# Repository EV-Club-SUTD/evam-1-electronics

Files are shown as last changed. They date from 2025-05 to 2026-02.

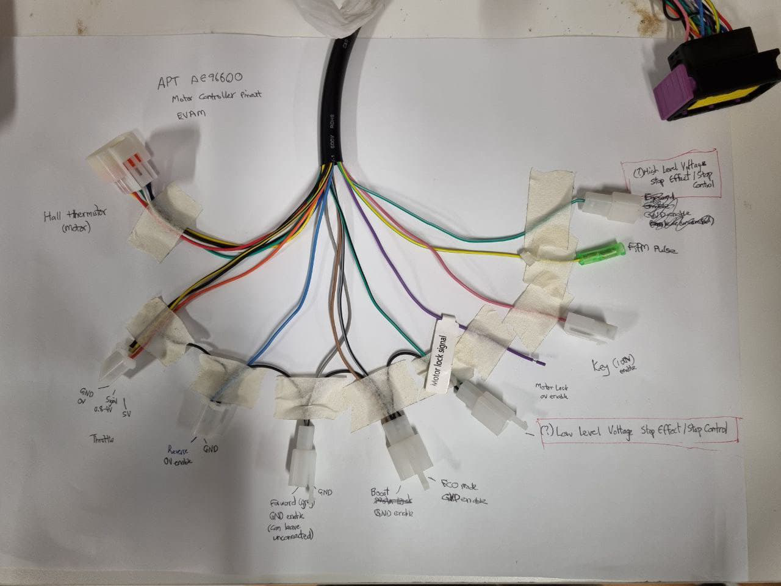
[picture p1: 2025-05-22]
docs/Datasheets/Motor Controller (QS Motor)/Original Controller Wire Harness Pinout.jpg

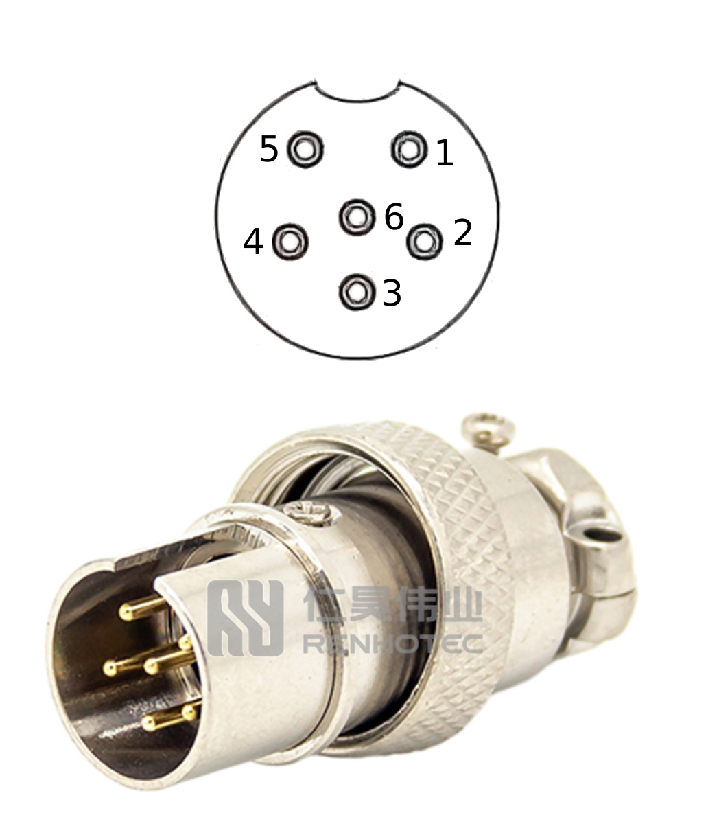
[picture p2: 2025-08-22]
docs/Wire Harness Diagrams/Master-Cable/img/GX16-Rev-pinout-cable.png

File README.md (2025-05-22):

# EVAM 1 Electronics Modules

> Design and manufacturing files for the EVAM 1's electrical and CAN bus system

<p align="center">

</p>

- [x] 🏎️ Automotive Hardware
- [ ] 🛞 Automotive Software
- [ ] 🖥️ Supporting Software and Simulations
- [ ] 📚 Code Library
- [ ] 🛠 Helper Script
- [x] 📖 Documentation / Datasheets
- [ ] ❓ Miscellaneous / Uncategorized

This repository contains the hardware design and manufacturing files for the EVAM 1's electrical system.  

## Directories

* `CANBus 2/Design` - Design files in KiCAD format
    * `/APPS` - Throttle position sensor PCB
    * `/BMS` - Battery Management System PCB
    * `/ECU` - Engine Control Unit PCB
    * `/HUD` - Heads up Display PCB
    * `/MCU_Double` - Motor Control Unit, double motor (for front motors)
    * `/MCU_Single` - Motor Control Unit, single motor (for rear motors)
    * `/SAS` - Steering Angle Sensor, originally meant for torque vectoring. Currently not used
* `CANBus 2/Manufacturing` - Manufacturing files (BOM, placement, and Gerbers)
* `CANBus 2/Electrical Layout` - Electrical layout design files, including block diagrams, to describe the high level overview of the entire electrical system
* `CANBus 2/Harness` - Cable harness design files and pictorial diagrams
* `Datasheets` - All the datasheets for the various components employed in the vehicle

## Documentation

Please refer to EVAM internal OneDrive for further documentation, including specific datasheets on the electrical system components

## Caveats

No known caveats yet

## Known issues

No known issues yet

## Contributing

If you encounter any issues with this repository, please do not hesitate to open an issue.

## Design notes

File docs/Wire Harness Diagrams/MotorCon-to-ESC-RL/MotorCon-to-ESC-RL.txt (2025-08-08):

Delphi / Aptiv 211PC249S0031 -> D
Molex KK 254 -> M
JST RCY -> J
DJ7061Y-2.3-11/21 -> H for hall sensor
    Connector side: 2 tabs facing up, numbered 1-6 from left to right, top to bottom. 

D C8 -> M 7 BLACK
D C7 -> H 1 YELLOW
D B8 -> H 5 WHITE
D A8 -> H 4 RED
D A7 -> H 3 BLUE
D B7 -> H 2 GREEN
D B6 -> M 3 YELLOW/GREEN
D A5 -> M 6 BROWN
D B5 -> M 5 BLACK/GREY
D C5 NOT IMPLEMENTED, SUPPOSED TO BE MOTOR LOCK
D A4 -> M 1 GREEN/BLACK
D B4 -> M 8 SKYBLUE
D B3 -> M 4 YELLOW/BLACK
D B1 -> J 1 PINK -> RED

Alphabetical order:

D A4 -> M 1 GREEN/BLACK
D A5 -> M 6 BROWN
D A7 -> H 3 BLUE
D A8 -> H 4 RED
D B1 -> J 1 PINK -> RED
D B3 -> M 4 YELLOW/BLACK
D B4 -> M 8 SKYBLUE
D B5 -> M 5 BLACK/GREY
D B6 -> M 3 YELLOW/GREEN
D B7 -> H 2 GREEN
D B8 -> H 5 WHITE
D C5 NOT IMPLEMENTED, SUPPOSED TO BE MOTOR LOCK
D C7 -> H 1 YELLOW
D C8 -> M 7 BLACK

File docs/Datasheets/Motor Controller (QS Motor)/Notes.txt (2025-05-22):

Battery to 12V controller that we have:
https://www.aliexpress.com/item/32908843079.html?pdp_ext_f=%7B%22ship_from%22:%22%22,%22sku_id%22:%2265947884391%22%7D&sourceType=fd&&scm=1007.28480.226530.0&scm_id=1007.28480.226530.0&scm-url=1007.28480.226530.0&pvid=7cc42ead-edf1-4f54-b0ab-460614838952&utparam=%7B%22process_id%22:%22110%22,%22x_object_type%22:%22product%22,%22pvid%22:%227cc42ead-edf1-4f54-b0ab-460614838952%22,%22belongs%22:[%7B%22id%22:%22812237%22,%22type%22:%22dataset%22%7D],%22scm%22:%221007.28480.226530.0%22,%22tpp_buckets%22:%2221669%230%23186385%230_21669%234190%2319160%23261_15324%230%23132599%230%22,%22x_object_id%22:%2232908843079%22%7D&spm=a2g0o.11810135.productlist.0

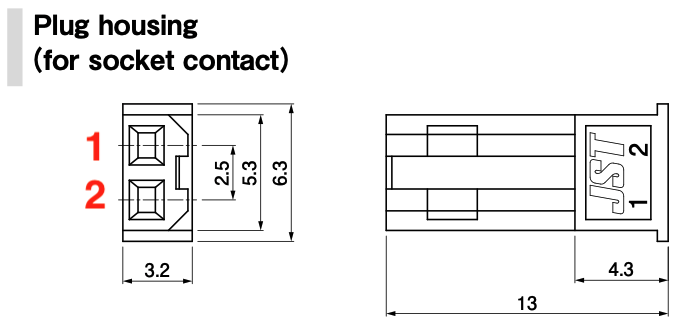
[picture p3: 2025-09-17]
docs/Wire Harness Diagrams/MotorCon-to-ESC-RL/img/JST-RCY-pinout-plug.png

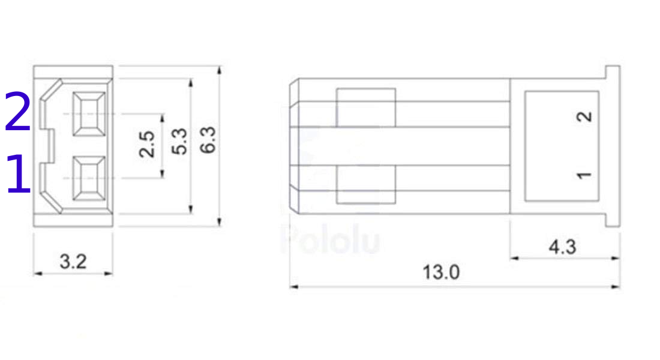
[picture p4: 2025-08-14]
docs/Wire Harness Diagrams/Master-Cable/img/JST-RCY-pinout.png

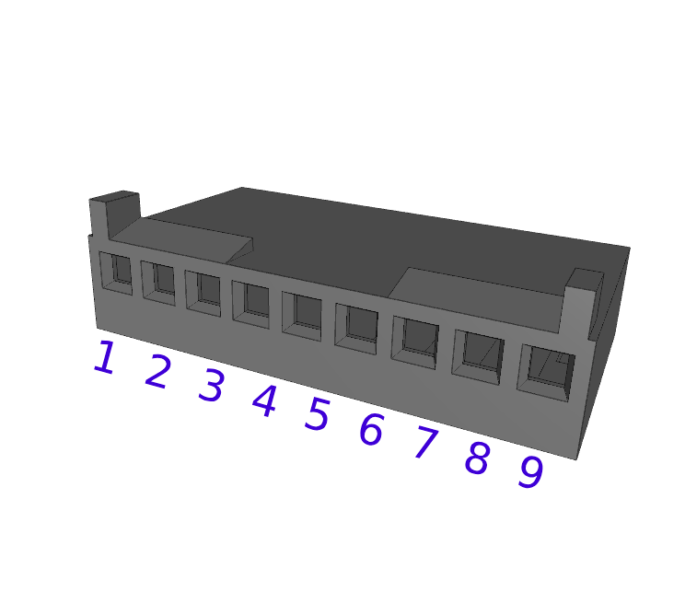
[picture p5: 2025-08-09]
docs/Wire Harness Diagrams/MotorCon-to-ESC-RL/img/MolexKK254-9-pinout.png

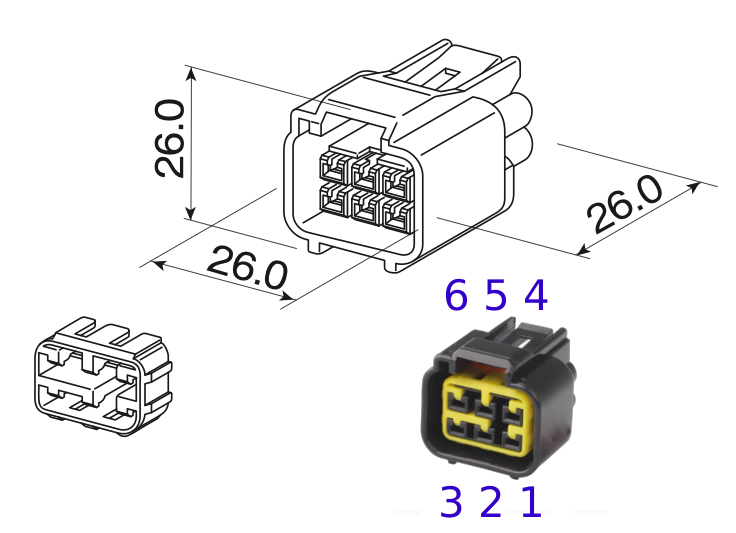
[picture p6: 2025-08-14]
docs/Wire Harness Diagrams/Master-Cable/img/FW-C-6F-B-pinout.png

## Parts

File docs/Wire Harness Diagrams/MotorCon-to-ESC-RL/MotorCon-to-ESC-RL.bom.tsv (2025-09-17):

Id | Description | Qty | Unit | Designators | Manufacturer | MPN | Supplier | SPN
1 | Cable, 1 x 22 AWG | 0.1 | m | W2
2 | Connector, Aptiv SICMA, Female, 24 pins | 1 |  | C1 | Aptiv (formerly Delphi) | 211PC249S0031 | Mouser | 649-211PC249S0031
3 | Connector, Furukawa RFW, Female, 6 pins | 1 |  | C2 | Furukawa | FW-C-6F-B | Aliexpress | DJ7061Y-2.3-11
4 | Connector, Heat shrink solder joint, 22 AWG | 1
5 | Connector, JST RCY, Plug, 2 pins | 1 |  | C4 | JST | SYR-02T | DigiKey | 455-2653-ND
6 | Connector, Molex KK254, Female, 9 pins | 1 |  | C3 | Molex | 22013097 | DigiKey | WM2007-MD
7 | Wire, 22 AWG, BK | 1 | m | W1
8 | Wire, 22 AWG, BN | 0.5 | m | W1
9 | Wire, 22 AWG, BU | 0.5 | m | W1
10 | Wire, 22 AWG, GN | 0.5 | m | W1
11 | Wire, 22 AWG, GNBK | 0.5 | m | W1
12 | Wire, 22 AWG, GYBK | 0.5 | m | W1
13 | Wire, 22 AWG, PK | 0.5 | m | W1
14 | Wire, 22 AWG, RD | 0.5 | m | W1
15 | Wire, 22 AWG, VT | 0.5 | m | W1
16 | Wire, 22 AWG, WH | 0.5 | m | W1
17 | Wire, 22 AWG, YE | 0.5 | m | W1
18 | Wire, 22 AWG, YEBK | 0.5 | m | W1
19 | Wire, 22 AWG, YEGN | 0.5 | m | W1

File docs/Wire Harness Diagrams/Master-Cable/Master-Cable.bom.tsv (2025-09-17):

Id | Description | Qty | Unit | Designators | Manufacturer | MPN | Supplier | SPN
<<<<<<< HEAD
1 | Cable, 1 x 22 AWG | 0.5 | m | W10, W2, W4, W6, W7
2 | Cable, 2 x 22 AWG | 0.1 | m | W3
3 | Cable, 6 x 22 AWG | 0.5 | m | W1
4 | Connector, GX16-6 Reverse Type, Male, 6 pins | 1 |  | C1 | Renhotec | GX16-A-6-P | Aliexpress | 1005008016363970
5 | Connector, Heat shrink solder joint, 22 AWG | 6
6 | Connector, JST RCY, Female, 2 pins | 2 |  | C3, C5 | JST | SYR-02T | DigiKey | 455-2653-ND
7 | Connector, JST RCY, Male, 2 pins | 1 |  | C4 | JST | SYR-02T | DigiKey | 455-2653-ND
8 | Connector, M12 A-key, Female, 6 pins | 1 |  | C2 | CANZ | M12-S-GWB | Taobao
9 | Wire, 22 AWG, BN | 0.1 | m | W5
=======
1 | Cable, 1 x 22 AWG | 0.4 | m | W5, W6, W7, W8
2 | Cable, 2 x 22 AWG | 0.2 | m | W2, W9
3 | Cable, 6 x 22 AWG | 0.5 | m | W1
4 | Connector, E-Stop Switch, 22 AWG | 1
5 | Connector, Fork terminal, 22 AWG, BK | 1
6 | Connector, Fork terminal, 22 AWG, RD | 1
7 | Connector, GX16-6 Reverse Type, Male, 6 pins | 1 |  | C1 | Renhotec | GX16-A-6-P | Aliexpress | 1005008016363970
8 | Connector, Heat shrink solder joint, 22 AWG | 6
9 | Connector, JST RCY, Plug, 2 pins | 4 |  | C4, C5, C7, C8 | JST | SYR-02T | DigiKey | 455-2653-ND
10 | Connector, JST RCY, Receptacle, 2 pins | 2 |  | C3, C6 | JST | SYR-02T | DigiKey | 455-2653-ND
11 | Connector, M12 A-key, Female, 6 pins | 1 |  | C2 | CAZN | M12-S-GWB | Taobao
12 | Connector, exposed section, 22 AWG | 3
13 | Wire, 22 AWG, BK | 0.2 | m | W10, W4
14 | Wire, 22 AWG, BN | 0.1 | m | W4
15 | Wire, 22 AWG, RD | 0.2 | m | W10, W4
16 | Wire, 22 AWG, WH | 0.1 | m | W4
>>>>>>> 582522ff65bb673bbe9b758eed1d0406d6d0a58b

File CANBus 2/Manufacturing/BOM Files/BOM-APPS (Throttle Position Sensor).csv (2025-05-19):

Comment | Designator | Footprint | LCSC
8MHz | Y1 | Crystal_SMD_HC49-SD | C12674
0.1uF | C1,C2 | C_0603_1608Metric | C14663
22pF | C5,C6 | C_0603_1608Metric | C1653
MCP2515-xST | U1 | TSSOP-20_4.4x6.5mm_P0.65mm | C185941
120 | R3 | R_0603_1608Metric | C22787
10k | R4 | R_0603_1608Metric | C25804
Conn_01x03_Pin | J4 | Molex_KK-254_AE-6410-03A_1x03_P2.54mm_Vertical | C2982032
10uF/16V | C3 | CP_EIA-3216-18_Kemet-A | C7171
TJA1051T | U2 | SOIC-8_3.9x4.9mm_P1.27mm | C92211

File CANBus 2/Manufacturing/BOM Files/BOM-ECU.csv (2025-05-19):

Comment | Designator | Footprint | LCSC
8MHz | Y1 | Crystal_SMD_HC49-SD | C12674
MCP2515-xST | U1 | TSSOP-20_4.4x6.5mm_P0.65mm | C15193
0.1uF | C3,C4,C6 | C_0603_1608Metric | C1525
22pF | C1,C2 | C_0603_1608Metric | C1653
120 | R4 | R_0603_1608Metric | C22787
10k | R3 | R_0603_1608Metric | C25804
Conn_01x03_Pin | J1 | Molex_KK-254_AE-6410-03A_1x03_P2.54mm_Vertical | C2982032
10uF/16V | C5 | CP_EIA-3216-18_Kemet-A | C7171
24k/1W | R1,R2 | R_2512_6332Metric | C728156
SN74LVC1G14DBV | U4 | SOT-23-5 | C7835
6N137S | U3 | SMDIP-8_W9.53mm | C898988
TJA1051T | U2 | SOIC-8_3.9x4.9mm_P1.27mm | C92211

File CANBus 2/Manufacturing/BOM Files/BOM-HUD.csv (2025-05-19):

Comment | Designator | Footprint | LCSC
SN65HVD230 | U2 | SOIC-8_3.9x4.9mm_P1.27mm | C12084
SW_SPDT | SW1 | SW_SPDT_MT-0-103-F001-T000-RS | C1788498
1M | R6 | R_1206_3216Metric | C17927
10k | R1,R2,R3,R4,R5,R7 | R_0603_1608Metric | C25804
Conn_01x02_Pin | J5,J6,J7,J8 | Molex_KK-254_AE-6410-02A_1x02_P2.54mm_Vertical | C2982031
Conn_01x04_Pin | J4 | Molex_KK-254_AE-6410-04A_1x04_P2.54mm_Vertical | C2982033
Conn_01x09_Pin | J1 | Molex_KK-254_AE-6410-09A_1x09_P2.54mm_Vertical | C2982038

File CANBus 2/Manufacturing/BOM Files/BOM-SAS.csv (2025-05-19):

Comment | Designator | Footprint | LCSC
8MHz | Y1 | Crystal_SMD_HC49-SD | C12674
0.1uF | C1,C2 | C_0603_1608Metric | C14663
10uF | C3 | C_0805_2012Metric | C15850
22pF | C5,C6 | C_0603_1608Metric | C1653
MCP2515-xST | U2 | TSSOP-20_4.4x6.5mm_P0.65mm | C185941
120 | R2 | R_0603_1608Metric | C22787
10k | R1 | R_0603_1608Metric | C25804
Conn_01x03_Pin | J1 | Molex_KK-254_AE-6410-03A_1x03_P2.54mm_Vertical | C2982032
Conn_01x04_Pin | J2 | Molex_KK-254_AE-6410-04A_1x04_P2.54mm_Vertical | C2982033
TJA1051T | U1 | SOIC-8_3.9x4.9mm_P1.27mm | C92211

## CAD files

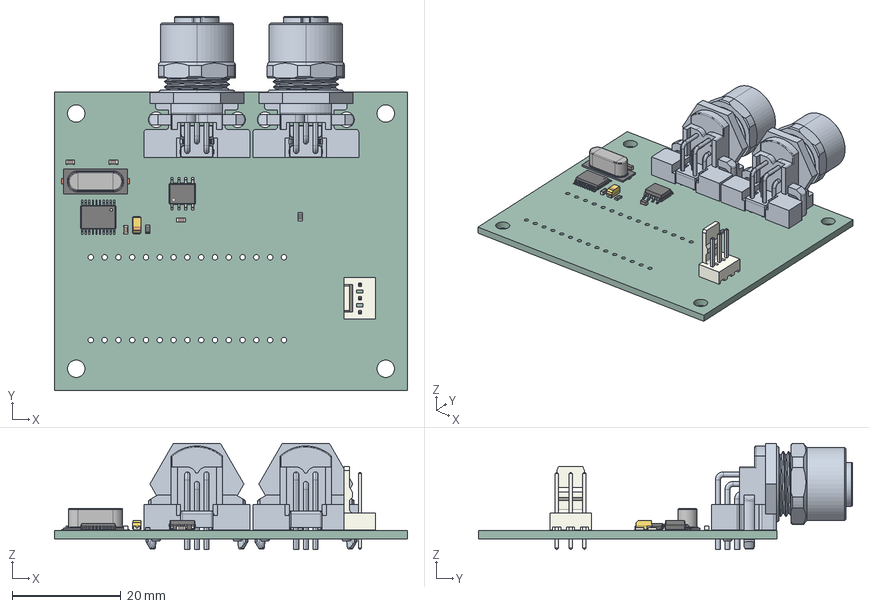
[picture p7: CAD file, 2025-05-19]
CANBus 2/Design/APPS (Throttle Position)/APPS (Throttle Position Sensor).step
65.0 x 68.9 x 19.6 mm
APPS (Throttle Position Sensor) PCB

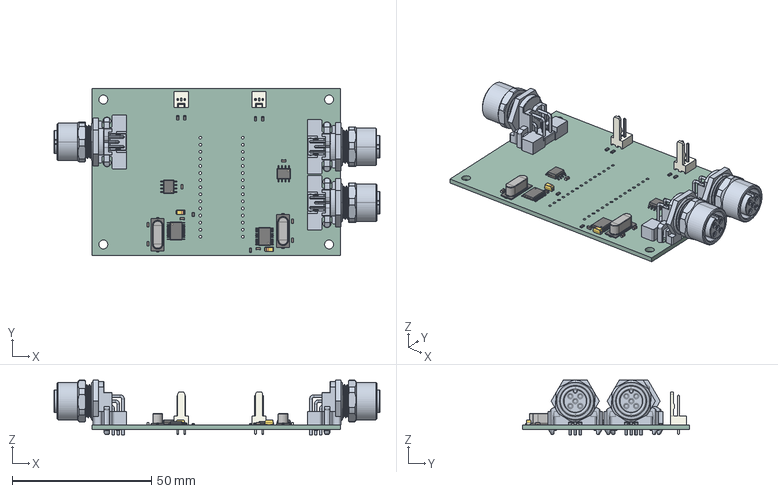
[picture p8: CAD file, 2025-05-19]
CANBus 2/Design/BMS/BMS.step
117.0 x 60.0 x 19.6 mm
BMS PCB

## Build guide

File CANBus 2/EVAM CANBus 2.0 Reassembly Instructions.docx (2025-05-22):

# EVAM CANBus 2.0 Reassembly Instructions

Last updated: 11 Feb 2025

Table of Contents

Version history

V1.0: First draft published 11 Feb 2025.

## 1 Setup Instructions

- Ensure that all high temperature works (e.g. Welding) on mainframe are completed before rewiring of car.
- Wiring can be done before the battery is placed back into the car. No need to install the battery first
- Remove the two seats (note that front seat has spacers for wires to run below, while the rear seat does not have spacers) to make room for wiring.
- If you need wiring guidance, please refer to the Wiring and Brake Overview Diagram (https://sutdapac-my.sharepoint.com/:b:/r/personal/ev_club_sutd_edu_sg/Documents/EVAM%201/EVAM/Motor,%20Controller,%20Battery/Wiring/EVAM%20Electrical,%20CANBU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) PDF file.

CRITICAL WARNING

- Rewiring can be dangerous if improperly done! There is a genuine risk of fire and electrical shock if wiring is not done properly once the battery is connected. Always double/triple check your connections once completed.
- The chassis is grounded at a 0V potential. This means that any stray wire that accidentally contacts the chassis may cause a serious short circuit incident!
- Always double check that there are ZERO frayed wires and take note that some of the dashboard elements such as the Estop signals are 100V signals directly coming from the battery.
- There HAVE BEEN incidents where the 100V Estop signal inadvertently touched the chassis resulting in an electrical arc incident, which thankfully was brief and did not result in serious harm. DO NOT be the first casualty!

## 2 High Power Lines Installation

The high-power lines are responsible for conducting large currents from the battery to the motors.

Ensure that the bus bar panel is screwed into the blast plate. There should be a wire for grounding the chassis. Uncoil all overlapping/intersecting wires.

Below shows a picture of the components on the bus bar panels. Black high-power lines leading to the motor controllers are labelled front, rear, left and right. Replace the labels if they are missing or broken.

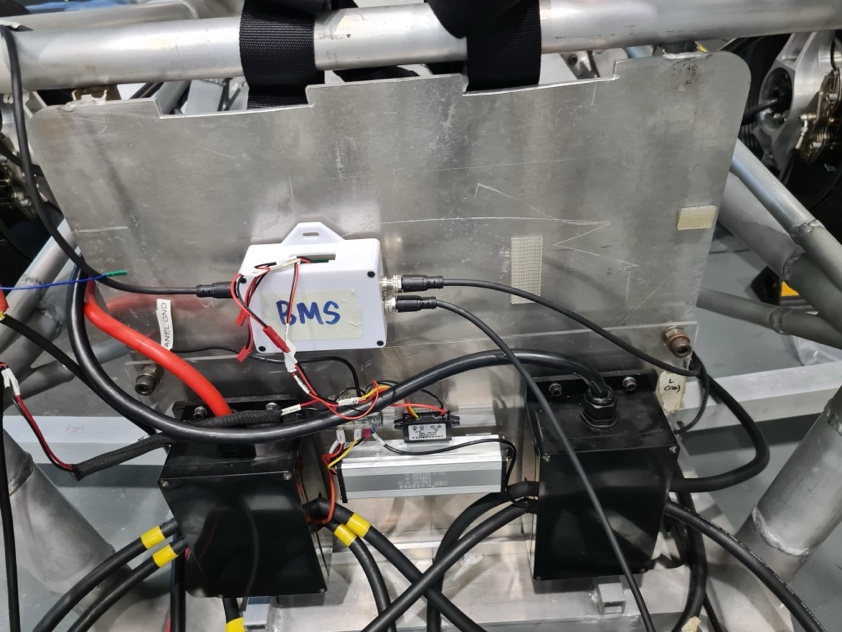
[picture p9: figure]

Figure 1: Bus bar panel mounted to the blast plate The BMS CAN module depicted in the picture is mounted later.

Figure 2: Diagram of the terminal block on the busbar panel

Within the busbar panel, there is a terminal block used to link some of the voltage lines together. This terminal block should eventually be replaced with something more robust.

The thin 100V lines serve 2 purposes: transport the 100V output directly from the battery to a 12V regulator to provide 12V electricals, and to provide the signal for motor Estop.

(insert wiring diagram on how cable is typically placed in the car)

## 3 Motor Controllers' installation

Attach motor controllers to main frame of car and wire the motors according to the color codes. Inspect all connectors and cables for motor controllers to ensure no wires are frayed.

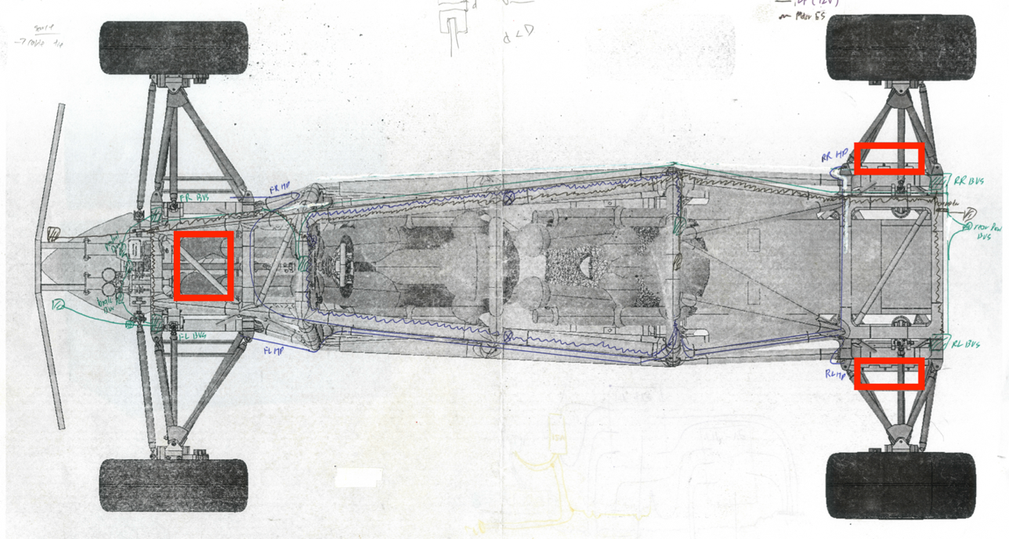
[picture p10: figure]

Figure 3: Motor controller locations

Motor controllers should be labelled appropriately with rear or front, as THEY HAVE DIFFERENT PINOUTS. Failure to maintain front/rear will result in failure of individual motor drivers.

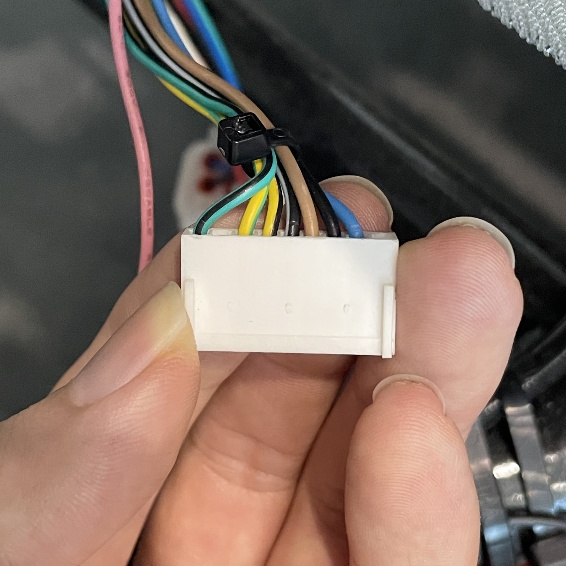
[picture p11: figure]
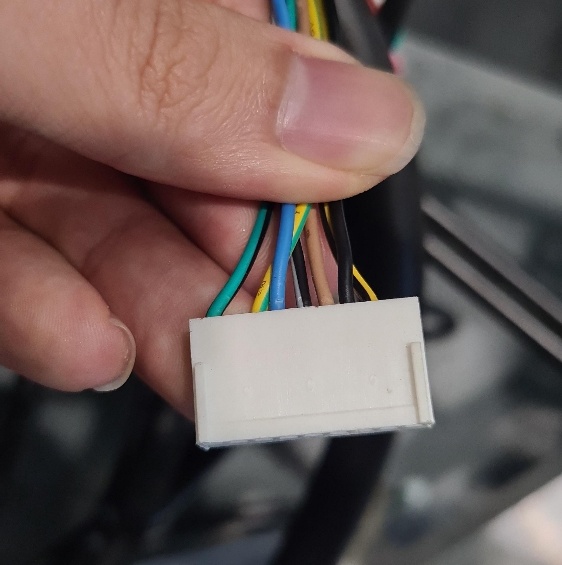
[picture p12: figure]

Figure 4 (left): example of a rear motor controller connector

Figure 5 (right): Example of a front motor controller

(insert picture on how to connect hall connector of motor controller to wheel hub motors)

(insert picture of high-power lines attached to motor controllers)

## 4 Understanding the Master Cable

The Master Cable is a specially made cable that runs the entire length of the vehicle, starting at the battery’s CAN connector and ends at the front dashboard, with a split in the middle to accommodate the battery Estop button in the middle of the vehicle.

This cable is designed to handle the following functions:

- Motor Estop
- Battery Estop
- Battery CAN bus

Figure 6: Basic hand drawn diagram of the Master Cable

The Master Cable should be replaced as soon as possible with a more professional solution as the bend radii of several inner cables are too short, potentially causing breakages and dangerous operating conditions.

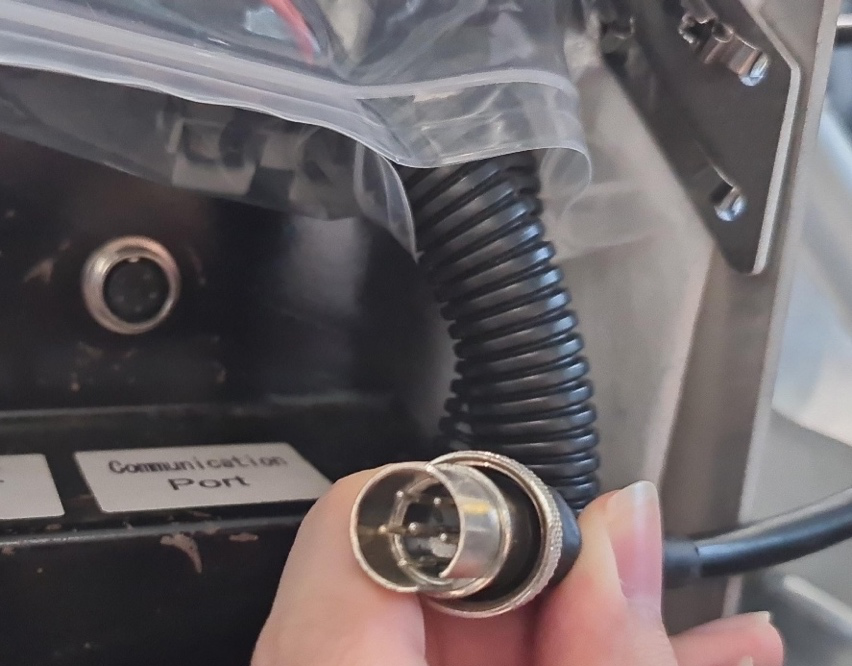
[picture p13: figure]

Figure 7: Battery CAN connector

The Master Cable chiefly contains the following signals stemming from the Battery CAN Connector (see above figure).

- Pin 5: CAN High
- Pin 6: CAN Low
- Pin 3: unknown red cable (possibly 100V)
- Pin 4: unknown black cable (possibly GND)
- Pin 1: battery estop switch
- Pin 2: battery switch

This bundle is then carried through the middle of the vehicle where it interfaces with the battery Estop switch:

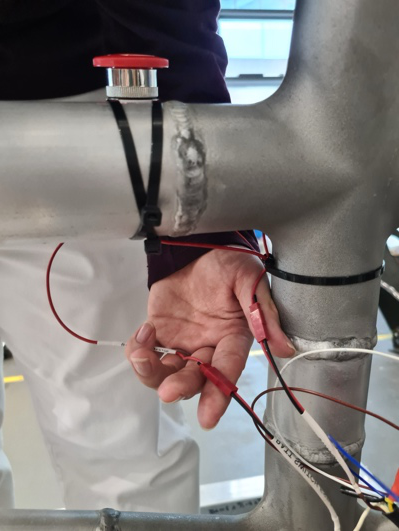
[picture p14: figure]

Figure 8: Battery Estop switch

After this, the bundle is split and additional cables travels to the front for the battery switch on the dashboard (turn knob).

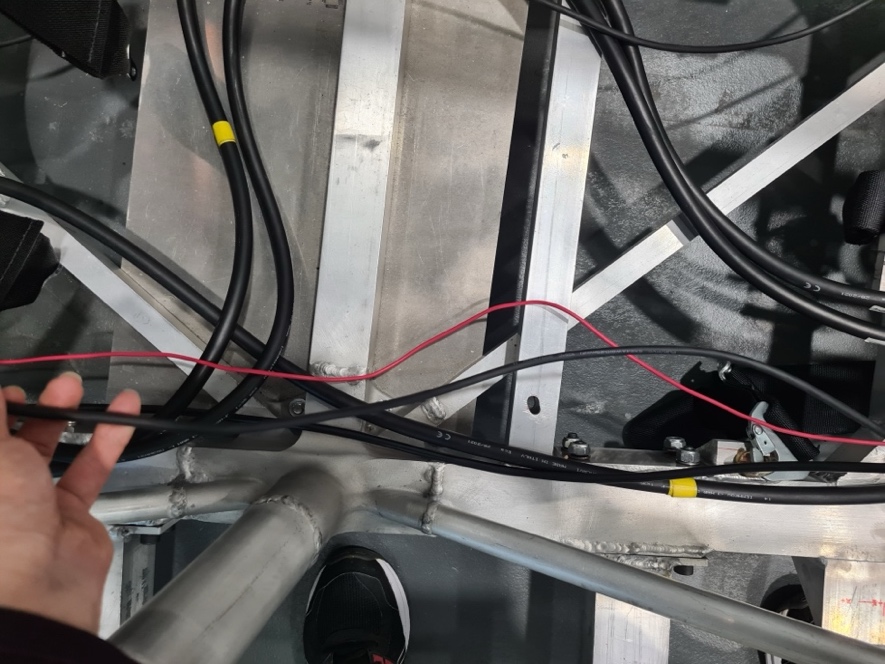
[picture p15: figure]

Figure 9: Black cable being held is the Master Cable as it travels from the middle Estop to the dashboard battery switch

## 5 CAN Modules Installation (8 Modules in Total)

### 5.1 BMS CAN module installation (rear)

Using a M2 Allen Key, unscrew the screws on the enclosures to access the PCB. Connect the wires through the holes found the enclosures and screw the lid back on.

Connect the 5V and 12V sense lines from the CAN bus panel to the BMS PCB.

Figure 10: BMS CAN node wiring before attachment to bus bar panel

Attach the Battery Side CAN using the shortest M12 cable possible to the Master Cable’s battery connector, which runs to the battery’s internal system

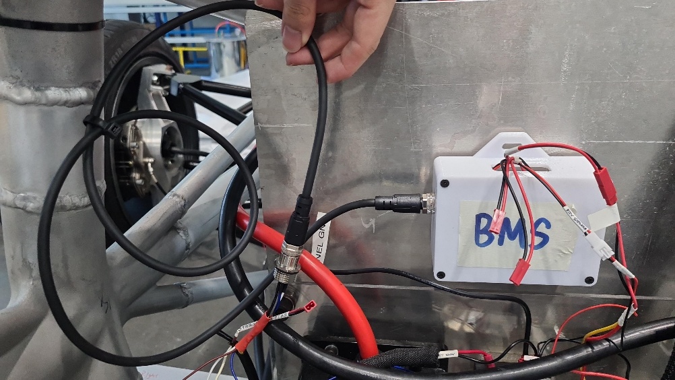
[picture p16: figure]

Figure 11: Connecting the BMS CAN port to the Master Cable

### 5.2 Motor CAN module installation (rear)

We will start with the motor node that has CAN termination, which has blackened corner marking on its top cover. This is installed on the rear left motor controller.

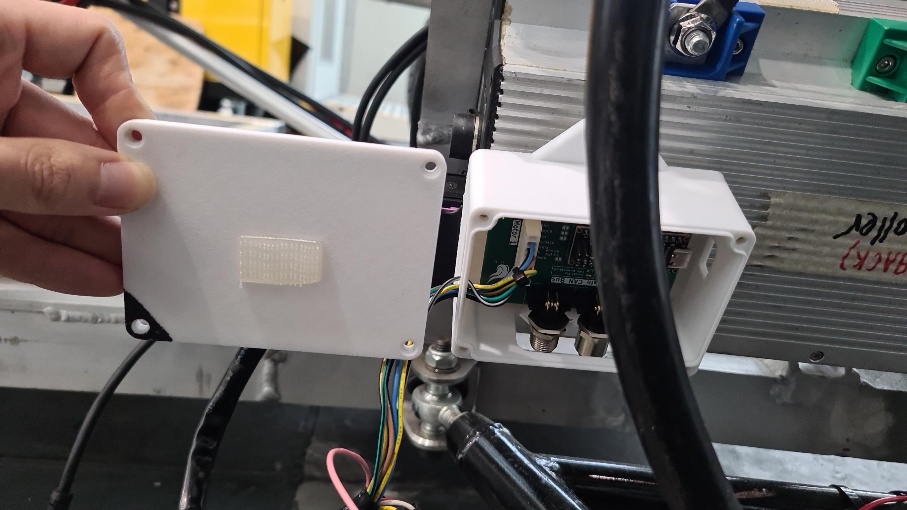
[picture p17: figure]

Figure 12: Rear left motor CAN node with black corner markings

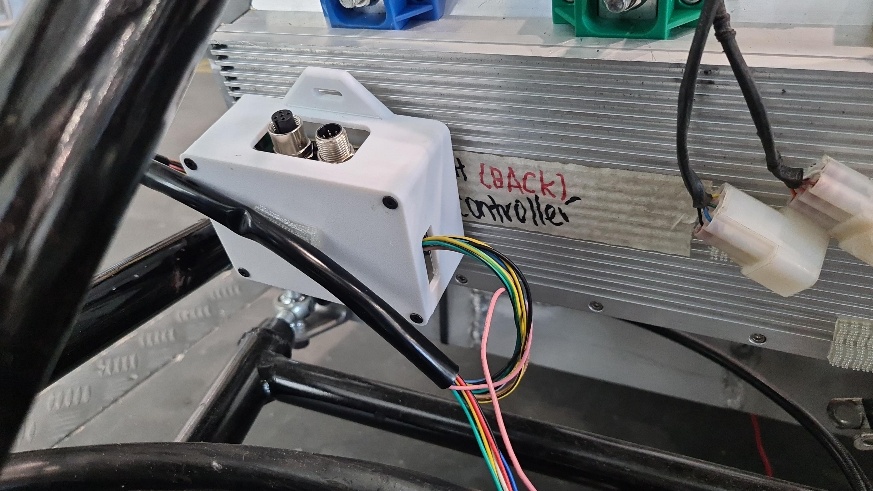
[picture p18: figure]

Figure 13: Rear right motor CAN node without markings

### 5.3 Motor CAN module installation (front)

The front of the vehicle has a dual motor CAN node. Connect both motor controllers to the CAN node and fasten them if necessary.

Figure 14: Mounting the Front Motor Controller

### 5.4 Throttle CAN and Steering Angle modules installation (front)

Attach the enclosures of the two modules to the front of the car near the brake and throttle pedals.

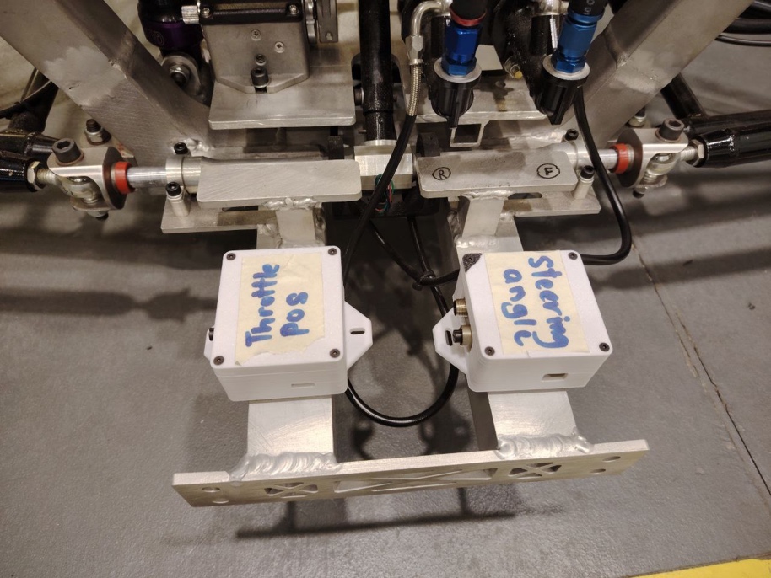
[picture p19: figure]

Figure 15: Placement of Throttle and Steering Angle Modules

Using a M2 Allen Key, unscrew the screws on the enclosures to access the PCB. Connect the wires through the holes found the enclosures and screw the lid back on.

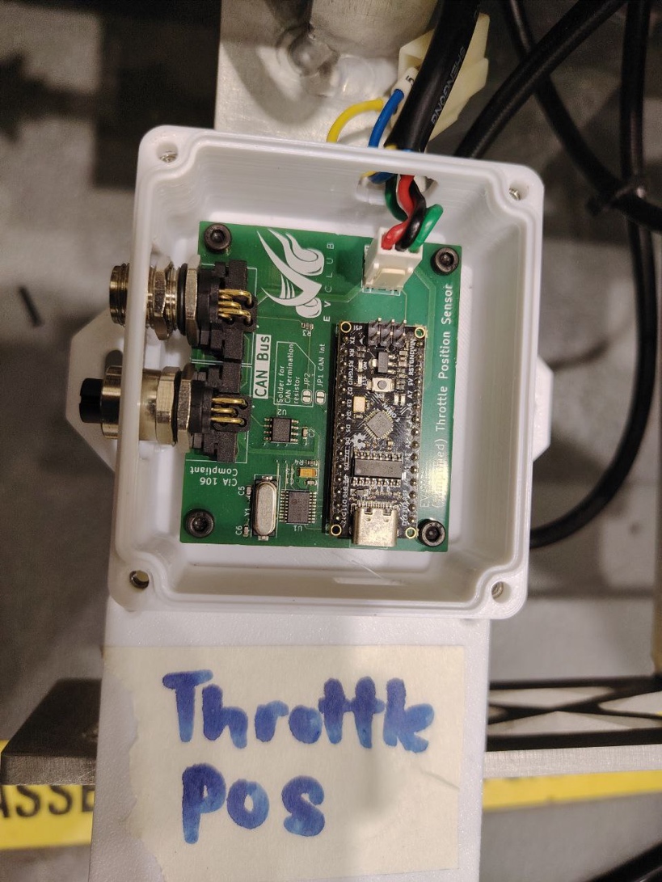
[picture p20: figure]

Figure 16: Throttle Position Sensor PCB wiring

### 5.5 HUD and ECU CAN modules installation (front)

Attach the enclosures of the two modules to the front of the car near the brake and throttle pedals. Wire up the HUD module appropriately according to the image below.

Take extra care to ensure that the right connectors are linked to the right sockets as the Estop is a 100V signal and WILL fry the module if connected incorrectly!!

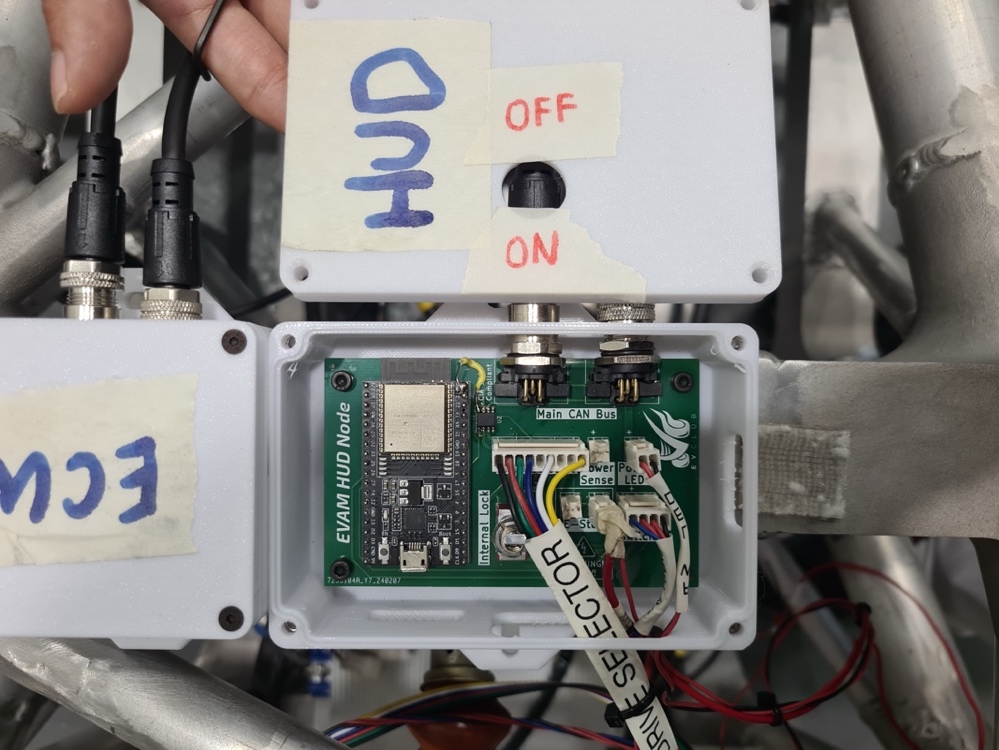
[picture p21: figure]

Figure 17: HUD PCB wiring. Note the masking taped wire is the high voltage Estop signal

Figure 18: ECU and HUD module placements

Once this is complete, we can begin wiring up all the modules.

### 5.6 CAN Bus Black Cables Connection to all nodes

1. Starting at the rear left motor node (which is a termination node, marked by the black edge colored by a marker), we run the cable to the rear right motor node.

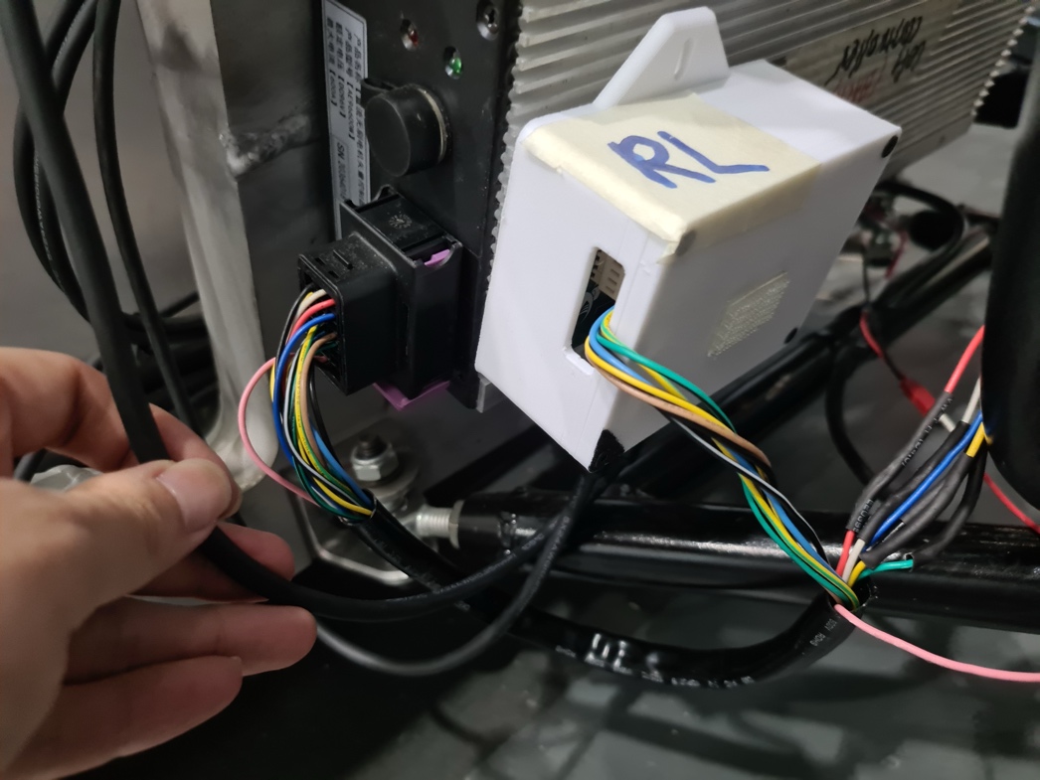
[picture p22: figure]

2. Run the cable from the rear left motor node to the rear right motor node across the top of the vehicle

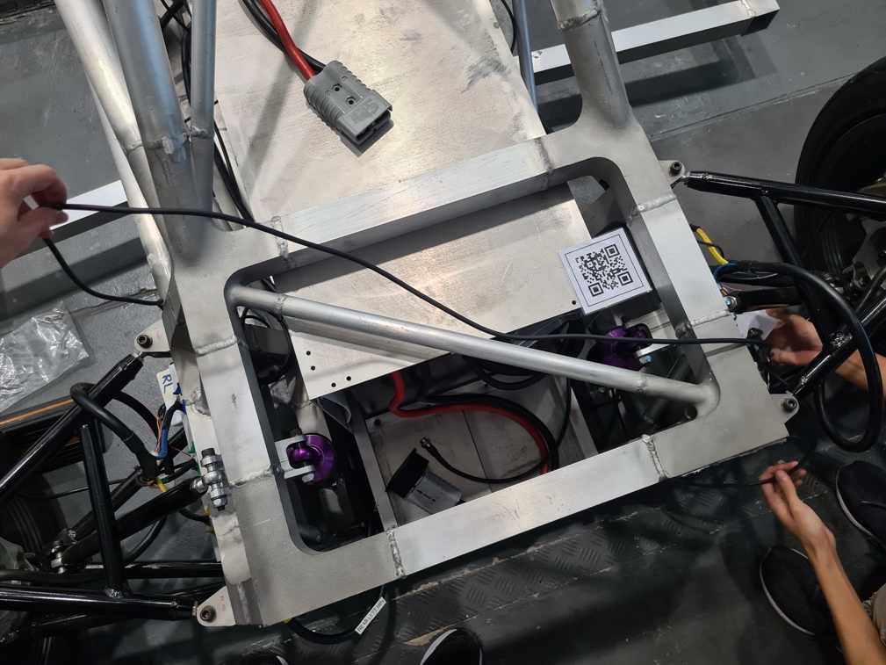
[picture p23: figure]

3. Run a long cable from the right rear motor module to the front of the vehicle and connect it to the HUD node.

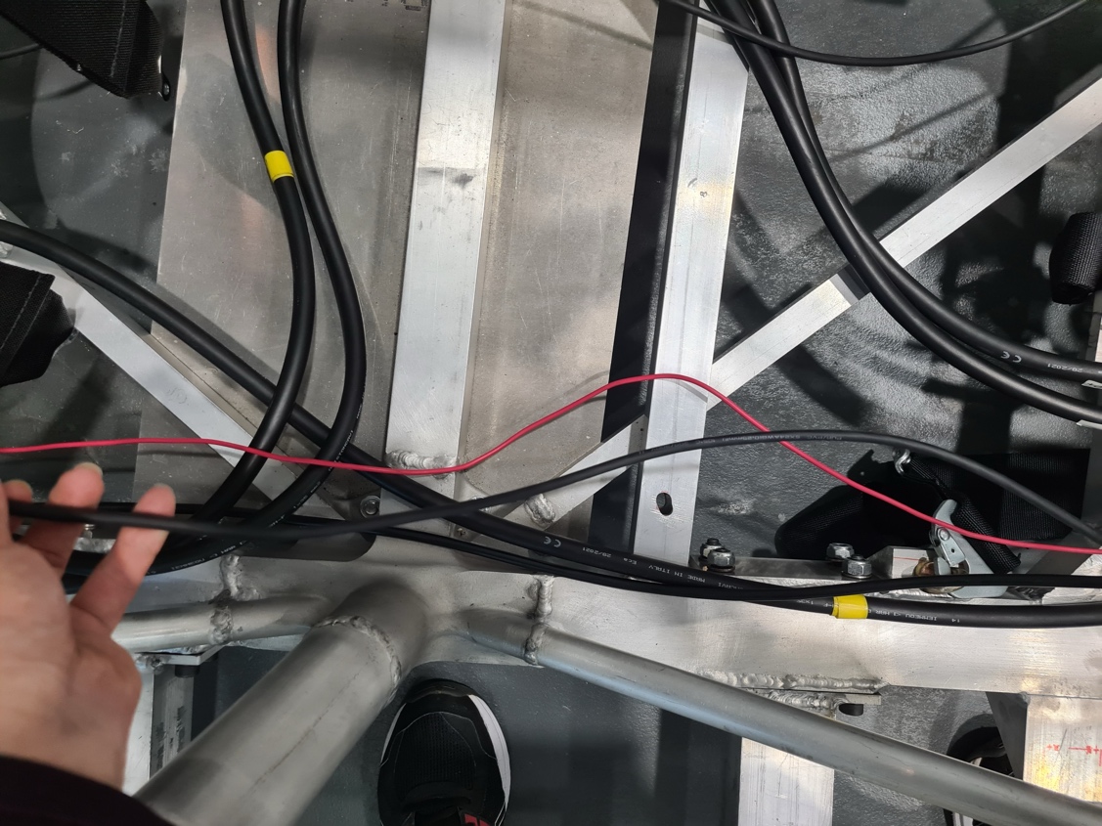
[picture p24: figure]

4. Use the shortest possible cable to connect the HUD and ECU modules together.
5. Run the ECU cable to the throttle position sensor
6. Link the throttle position sensor and the steering angle sensor modules together.
7. Run another medium length cable from the steering angle sensor to the front dual motor module

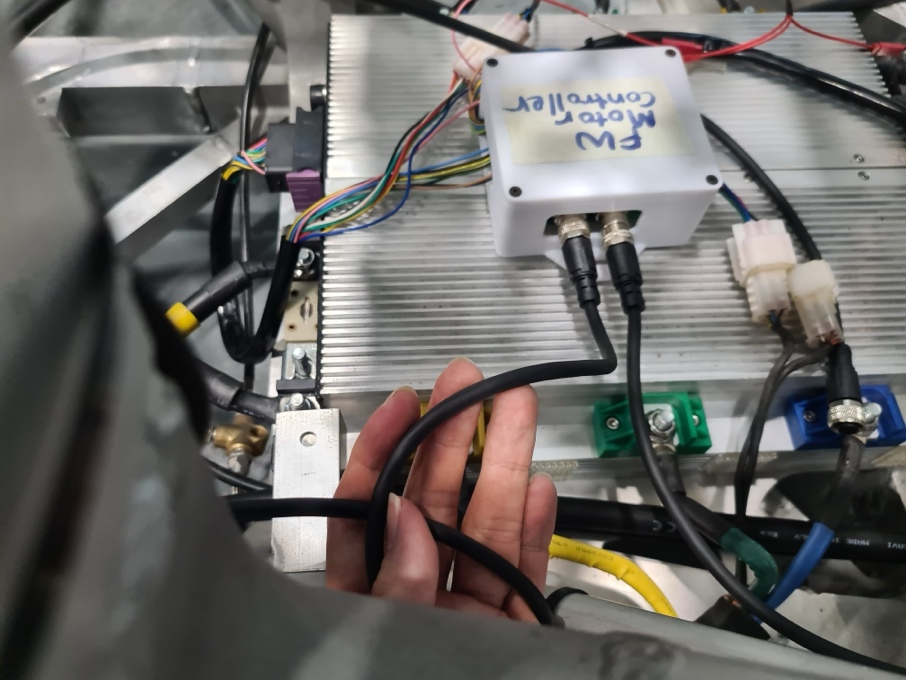
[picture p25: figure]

8. Wire the front dual motor module to the battery management system module. Finally, wire the BMS module to the rear left motor module mentioned in the 1st step and the CAN bus wiring is complete!

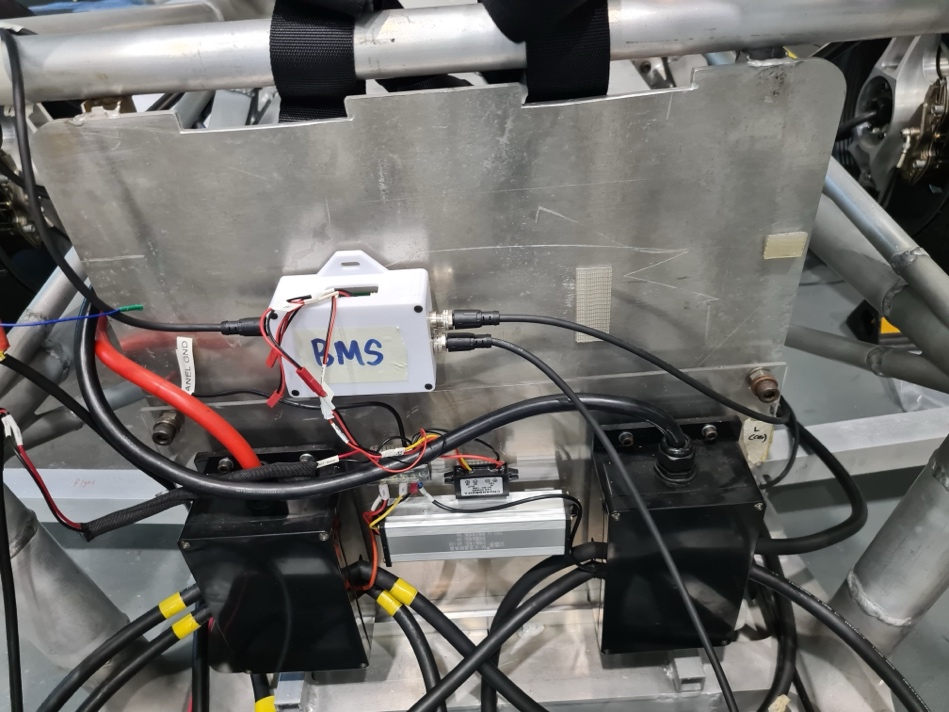
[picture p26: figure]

## 6 E-stop connection

### 6.1 Battery Estop

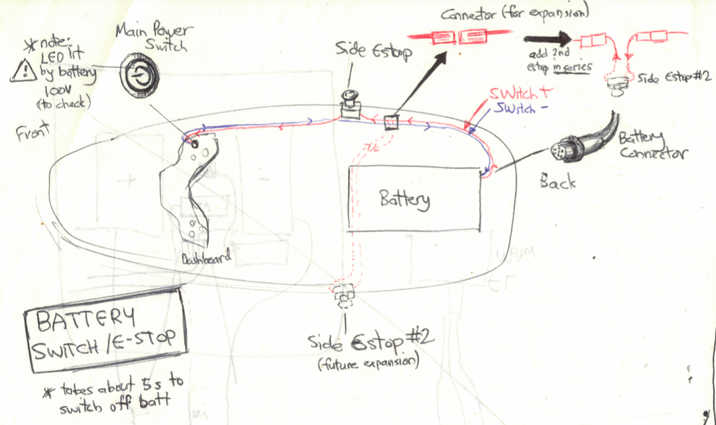
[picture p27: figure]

Figure 19: Battery E-stop diagram

The battery Estop system runs a single electrical signal in the following order:

- Battery Connector
- Estop button on the side of the vehicle
- Power switch on the front of the vehicle.

It is a relatively easy to install system as it only needs to connect at 3 points.

Figure 20: Rear of the Master Cable, which connects to the battery’s Communication Port

Once the Master Cable is installed into the vehicle (this is the cable that contains the battery signal connector, which is a proprietary “aviation style” connector instead of the standard M12 connector), the Estop button can be wired up as in the pictures below:

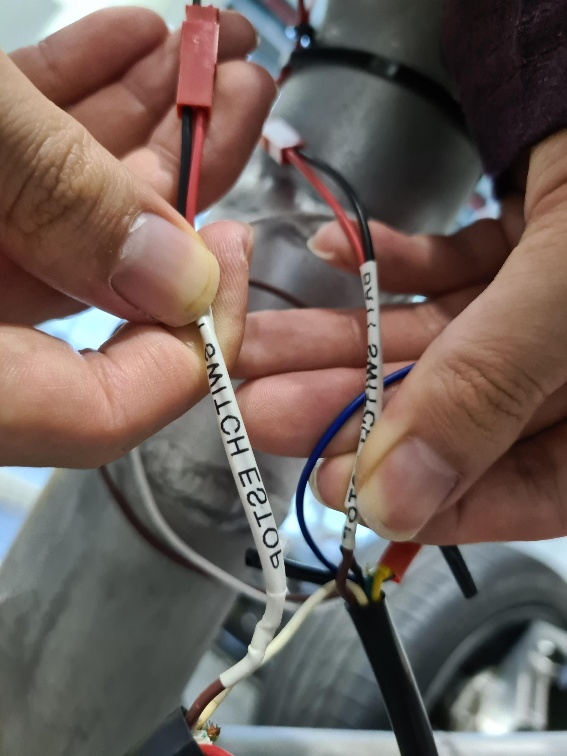
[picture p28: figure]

Figure 21 (left): Master Cable to Battery Estop switch on the side of the vehicle

Figure 22 (right): Master Cable to Battery Estop switch in the front of the vehicle

The red wire labelled ESTOP SWITCH must be wired to the front of the vehicle, where the red power switch is placed. The other wire labelled BATT ESTOP must be wired to the rear of the vehicle, where the battery’s signal cable is being plugged in.

### 6.2 Motor Estop

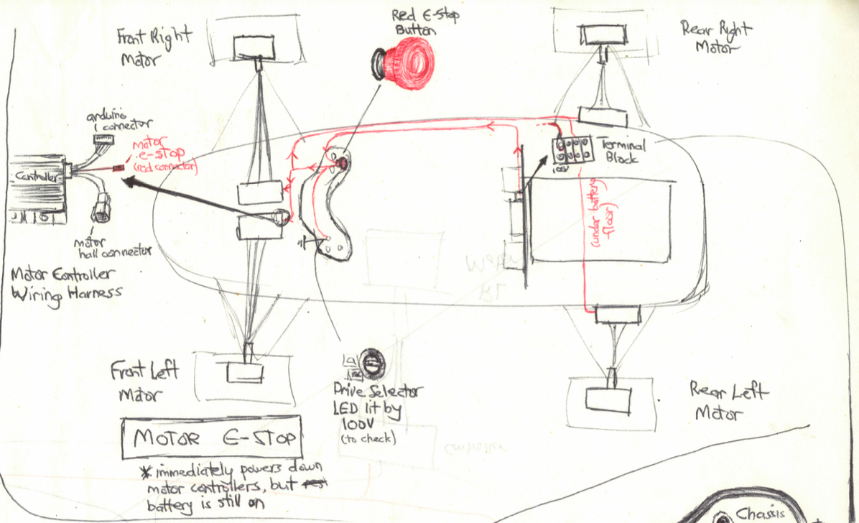
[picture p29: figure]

Figure 23: Motor Estop schematic

The Motor Estop is more complex, and is routed to the following places

- 100V from Terminal Block: This is where the 100V originates for the motor Estop signal
- Dashboard Estop button: root node, this button
- Front Left Motor Controller
- Front Right Motor Controller
- Rear Right Motor Controller
- Rear Left Motor Controller

The Motor Estop system is responsible for allowing the driver to assert a stop signal to all the motor controllers, allowing them to go into standby mode without having to power off the entire vehicle.

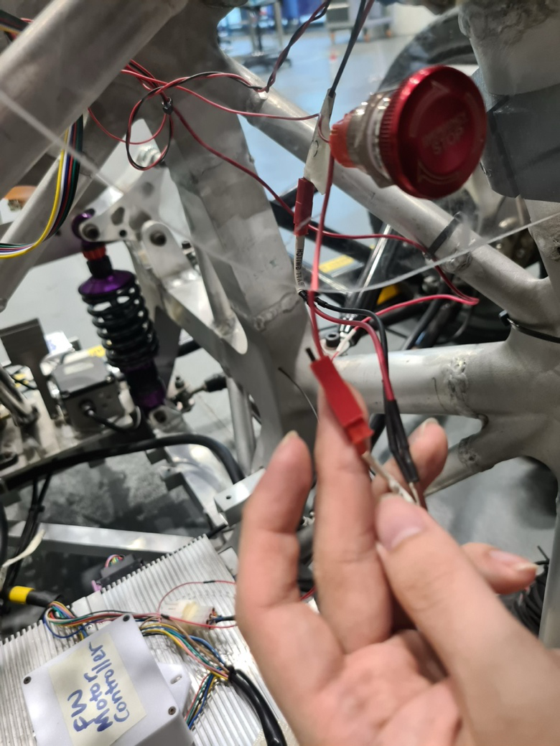
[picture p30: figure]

Figure 24: Front motor Estop button wiring

Figure 25: Front motor controllers wired to front Estop switch

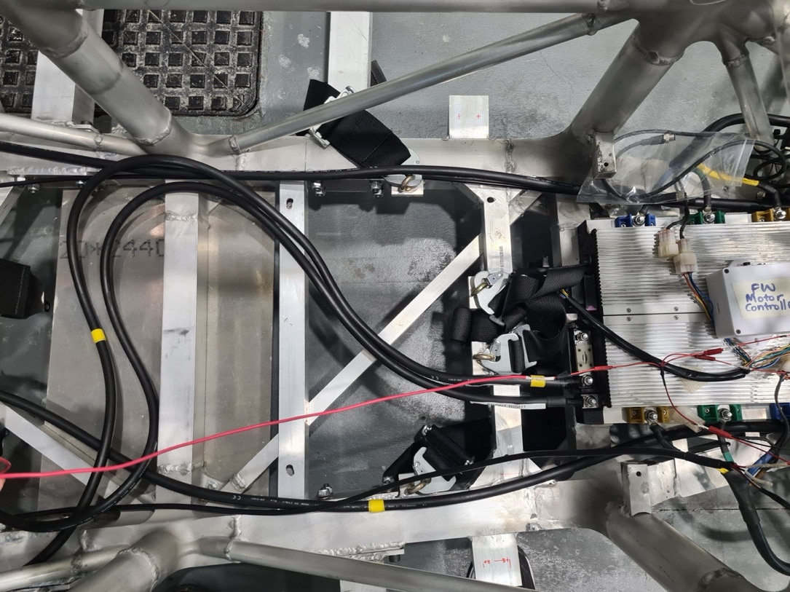
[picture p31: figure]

Figure 26: Red cable which conducts the Motor Estop signal going from the front controllers to the rear. Note the splice on the right side of this image

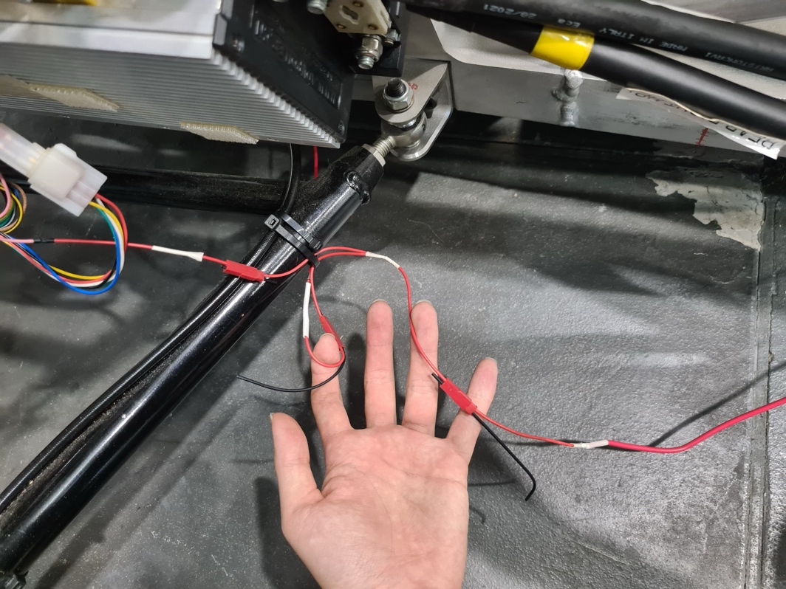
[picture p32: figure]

Figure 27: Motor Estop wire as it routes to the rear motor controllers, splitting at the right rear controller and proceeding to the left rear controller

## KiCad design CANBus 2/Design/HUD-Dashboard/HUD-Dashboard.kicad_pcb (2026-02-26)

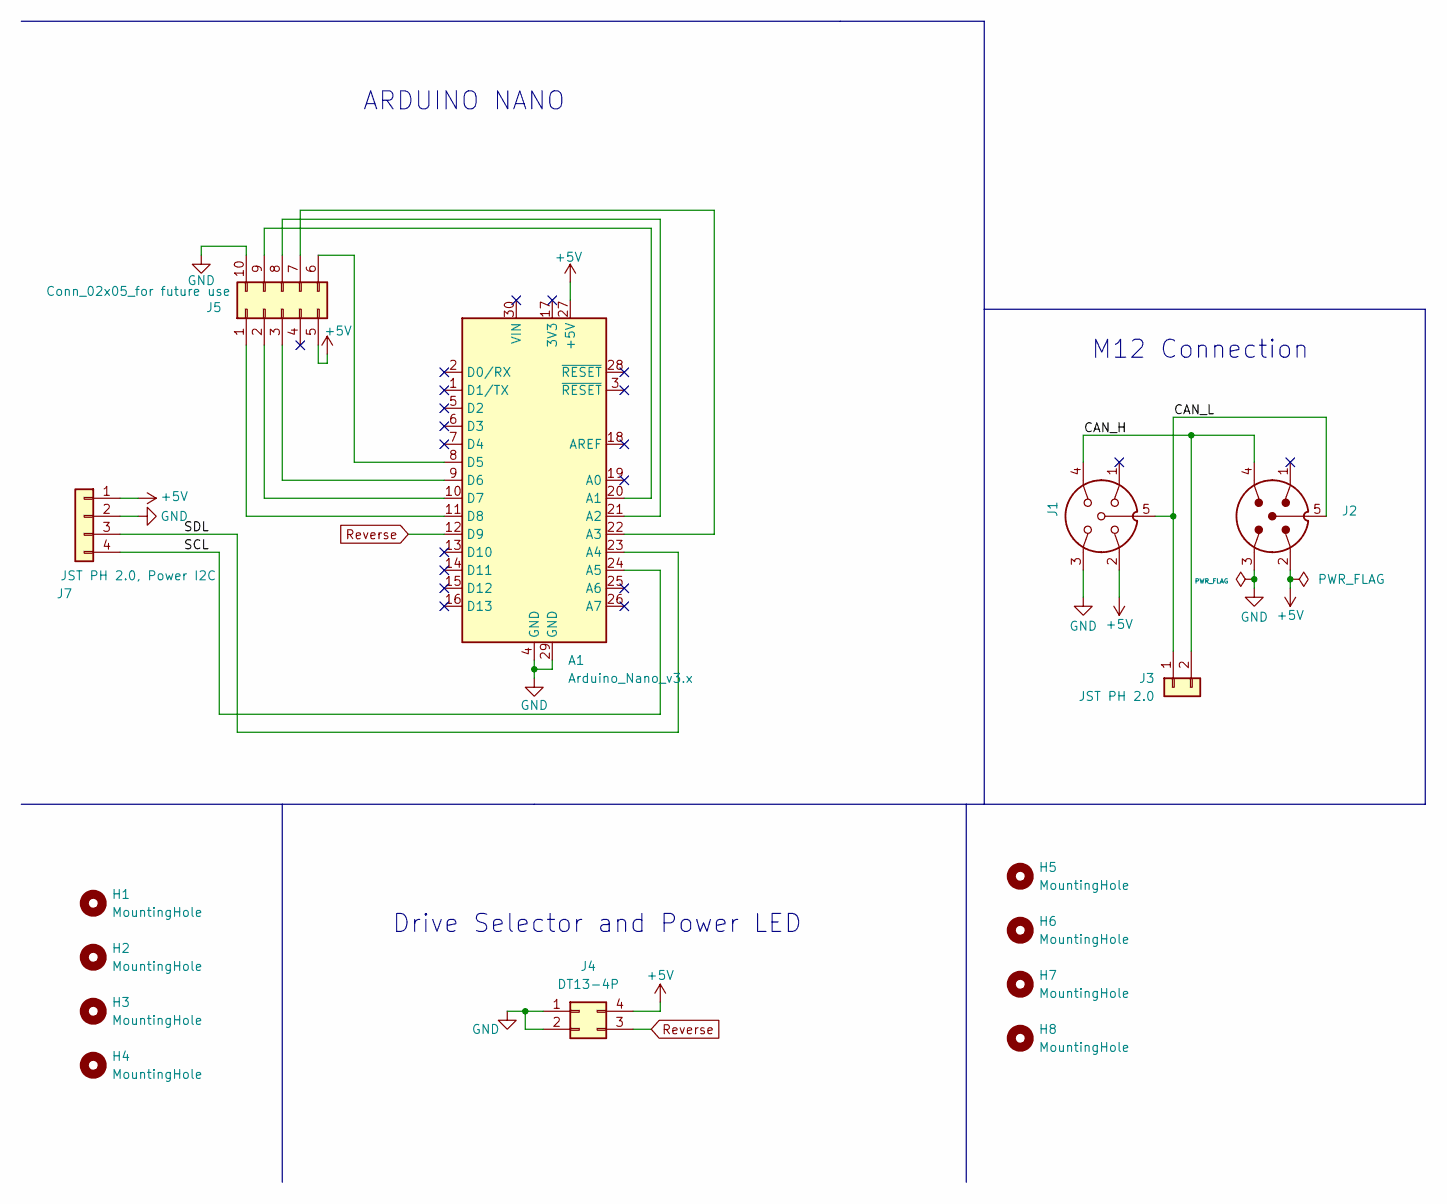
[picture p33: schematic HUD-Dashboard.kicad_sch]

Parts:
A1: Arduino_Nano_v3.x; Arduino_Nano
H1, H2, H3, H4, H5, H6, H7, H8: MountingHole; MountingHole_3.2mm_M3_ISO14580
J1: T4145015051-001; M12-S5A-GPL; PARTREV A
J2: TE_T4144015051-000; M12-P5A-GPL; PARTREV A
J3: JST PH 2.0; CONN-TH_2P-P2.00_ZX-HY2.0-2PZZ
J4: DT13-4P; TE_DT13-4P
J5: Conn_02x05_for future use; PinSocket_2x05_P2.54mm_Vertical
J7: JST PH 2.0, Power I2C; CONN-TH_4P-P2.00_ZX-HY2.0-4PZZ

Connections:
+5V: A1.27 (+5V), J1.2, J2.2, J4.4, J5.5, J7.1
/CAN_H: J1.4, J2.4, J3.2
/CAN_L: J1.5, J2.5, J3.1
/SCL: A1.24 (A5), J7.4
/SDL: A1.23 (A4), J7.3
GND: A1.4 (GND), A1.29 (GND), J1.3, J2.3, J4.1, J4.2, J5.10, J7.2
unnamed: A1.20 (A1), J5.9
unnamed: A1.21 (A2), J5.8
unnamed: A1.22 (A3), J5.7
unnamed: A1.8 (D5), J5.6
unnamed: A1.9 (D6), J5.3
unnamed: A1.10 (D7), J5.2
unnamed: A1.11 (D8), J5.1
Reverse: A1.12 (D9), J4.3

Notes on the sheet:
Drive Selector and Power LED
ARDUINO NANO
M12 Connection

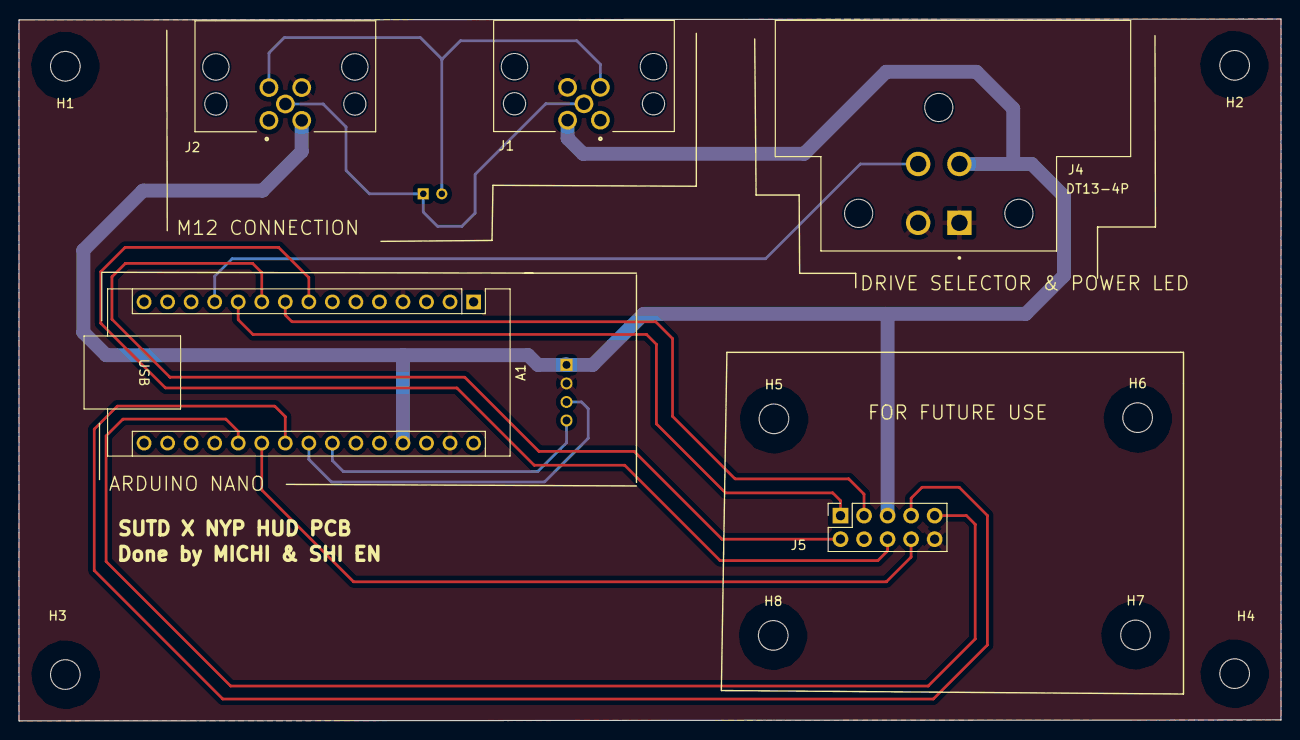
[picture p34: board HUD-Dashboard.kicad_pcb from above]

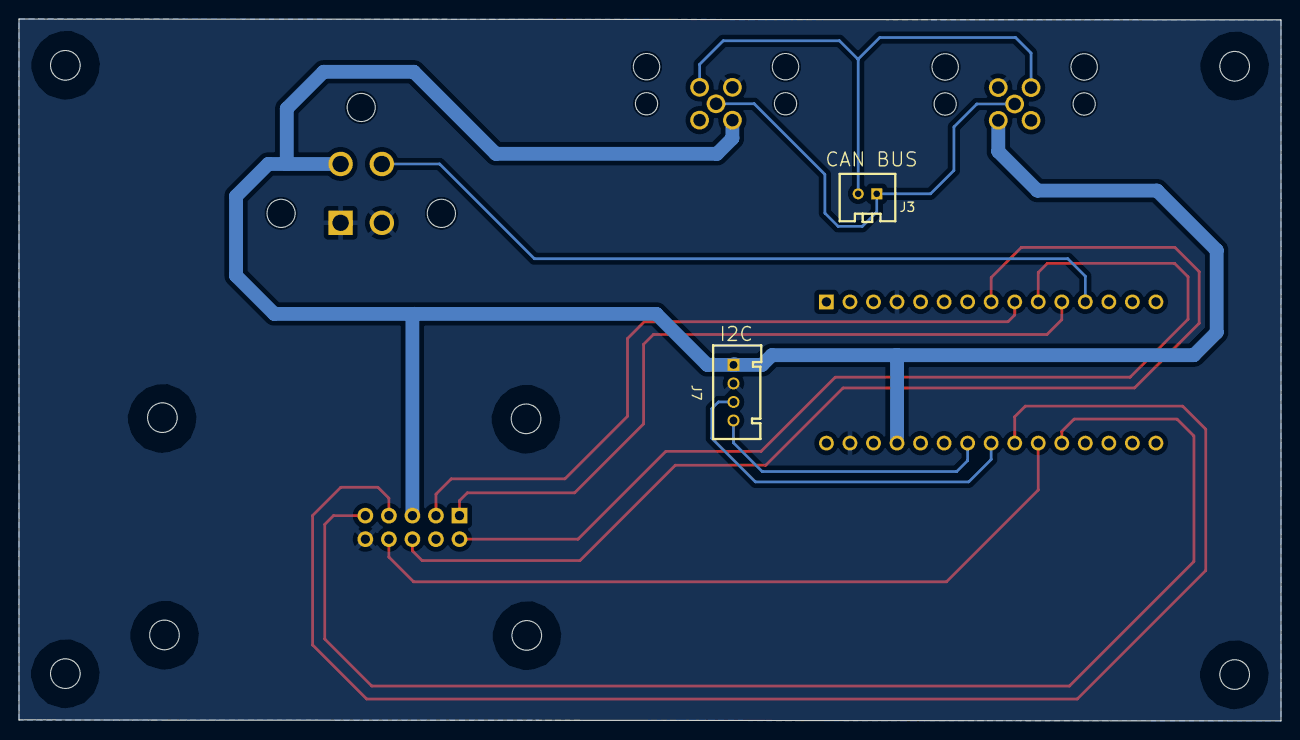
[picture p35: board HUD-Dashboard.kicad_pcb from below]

Board: 2 copper layers, 136.2 x 75.8 mm, 15 parts (2 on the bottom side), 14 nets.

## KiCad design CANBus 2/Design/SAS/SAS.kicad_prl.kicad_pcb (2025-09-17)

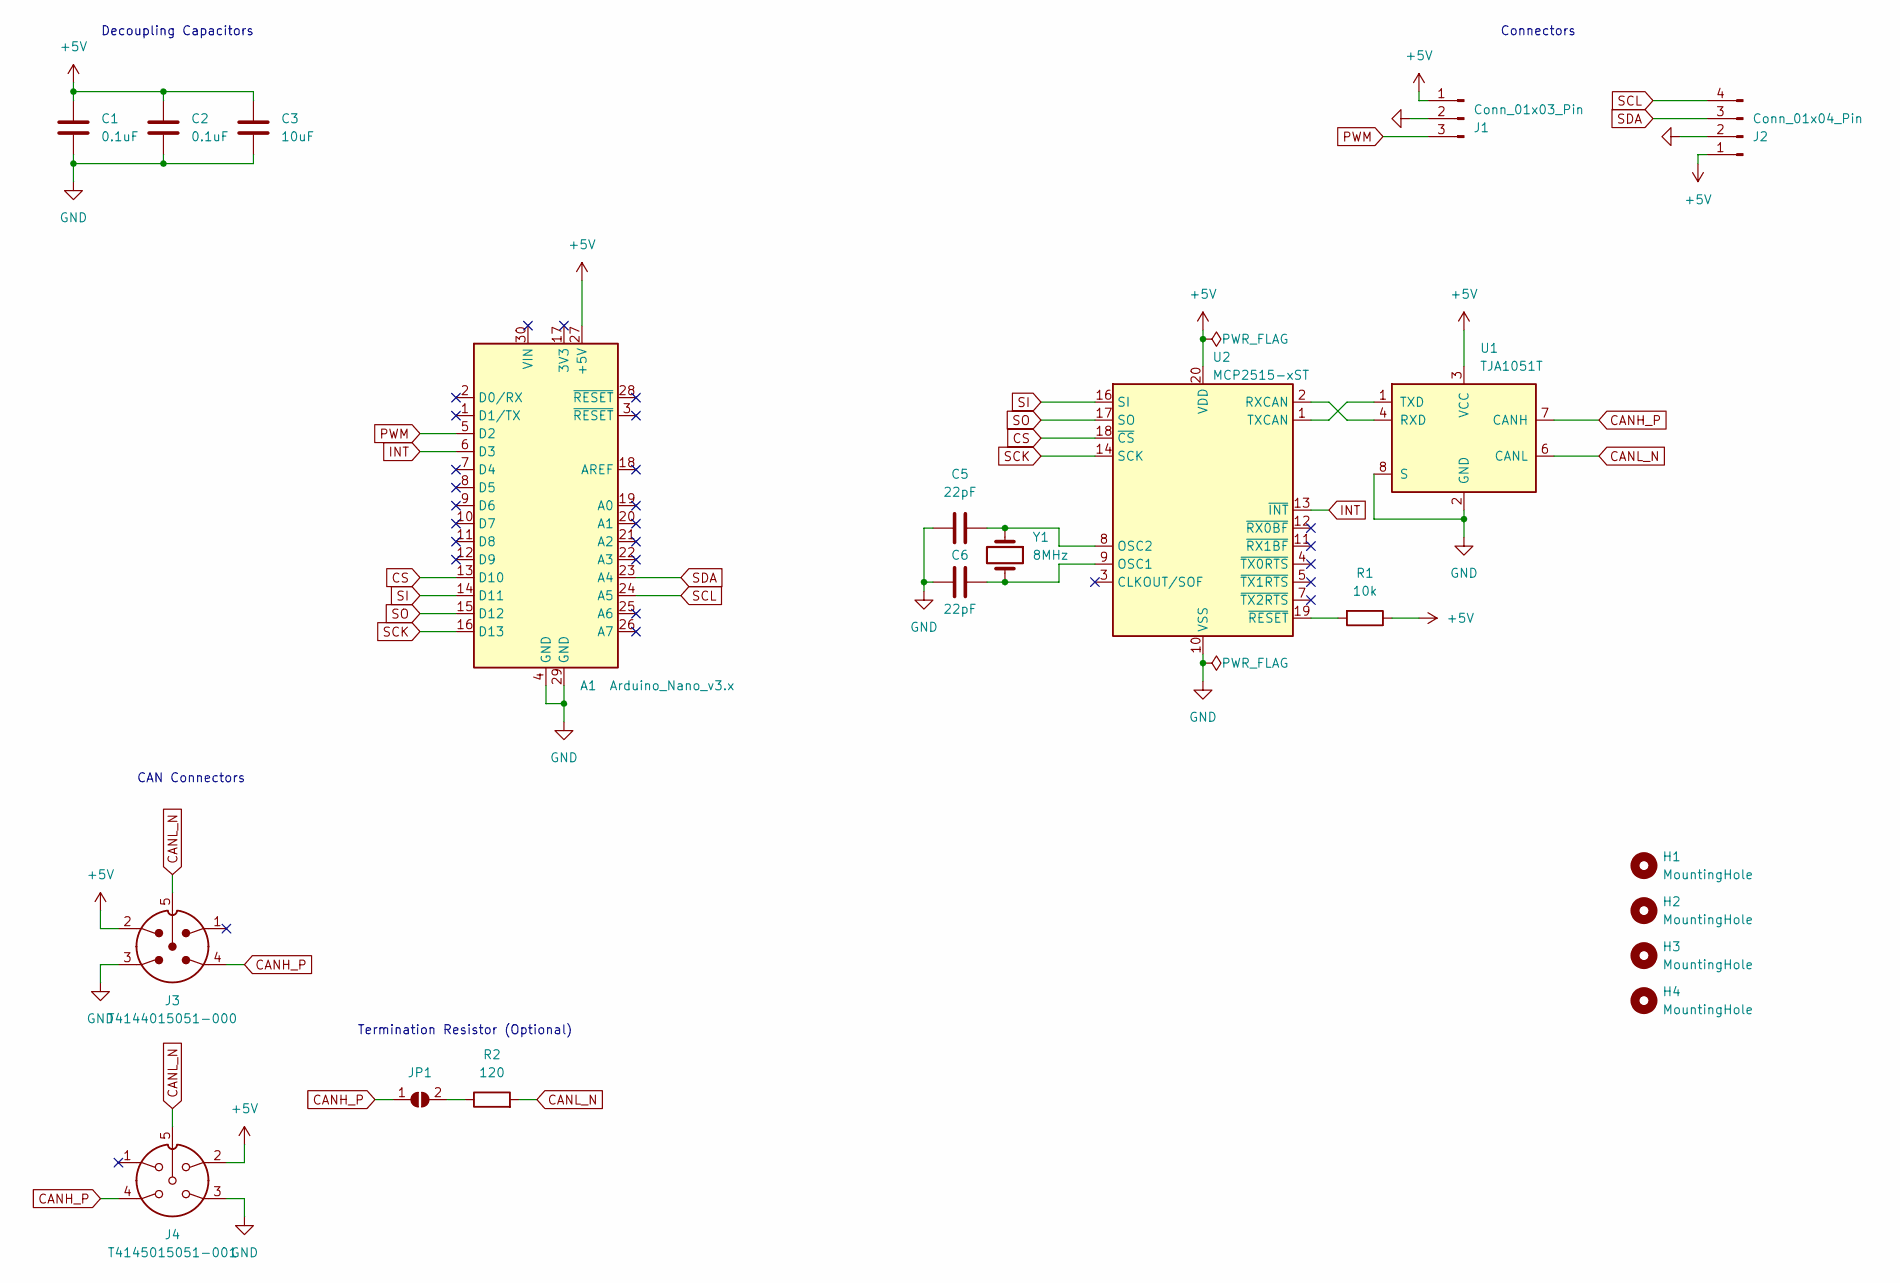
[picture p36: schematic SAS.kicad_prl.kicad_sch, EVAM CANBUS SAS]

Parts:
A1: Arduino_Nano_v3.x; Arduino_Nano
C1, C2: 0.1uF; C_0603_1608Metric
C3: 10uF; C_0805_2012Metric
C5, C6: 22pF; C_0603_1608Metric
H1, H2, H3, H4: MountingHole; MountingHole_3.2mm_M3_ISO14580
J1: Conn_01x03_Pin; Molex_KK-254_AE-6410-03A_1x03_P2.54mm_Vertical
J2: Conn_01x04_Pin; Molex_KK-254_AE-6410-04A_1x04_P2.54mm_Vertical
J3: T4144015051-000; M12-P5A-GPL; PARTREV A
J4: T4145015051-001; M12-S5A-GPL; PARTREV A
JP1: Jumper_2_Open; SolderJumper-2_P1.3mm_Open_RoundedPad1.0x1.5mm
R1: 10k; R_0603_1608Metric
R2: 120; R_0603_1608Metric
U1: TJA1051T; SOIC-8_3.9x4.9mm_P1.27mm
U2: MCP2515-xST; TSSOP-20_4.4x6.5mm_P0.65mm
Y1: 8MHz; Crystal_SMD_HC49-SD

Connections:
+5V: A1.27 (+5V), C1.1, C2.1, C3.1, J1.1, J2.1, J3.2, J4.2, R1.1, U1.3 (VCC), U2.20 (VDD)
CANH_P: J3.4, J4.4, JP1.1 (A), U1.7 (CANH)
CANL_N: J3.5, J4.5, R2.2, U1.6 (CANL)
CS: A1.13 (D10), U2.18 (~CS)
GND: A1.4 (GND), A1.29 (GND), C1.2, C2.2, C3.2, C5.1, C6.2, J1.2, J2.2, J3.3, J4.3, U1.2 (GND), U1.8 (S), U2.10 (VSS)
INT: A1.6 (D3), U2.13 (~INT)
unnamed: JP1.2 (B), R2.1
unnamed: U1.4 (RXD), U2.2 (RXCAN)
unnamed: U1.1 (TXD), U2.1 (TXCAN)
unnamed: C6.1, U2.9 (OSC1), Y1.2
unnamed: C5.2, U2.8 (OSC2), Y1.1
unnamed: R1.2, U2.19 (~RESET)
PWM: A1.5 (D2), J1.3
SCK: A1.16 (D13), U2.14 (SCK)
SCL: A1.24 (A5), J2.4
SDA: A1.23 (A4), J2.3
SI: A1.14 (D11), U2.16 (SI)
SO: A1.15 (D12), U2.17 (SO)

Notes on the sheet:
Decoupling Capacitors
CAN Connectors
Termination Resistor (Optional)
Connectors

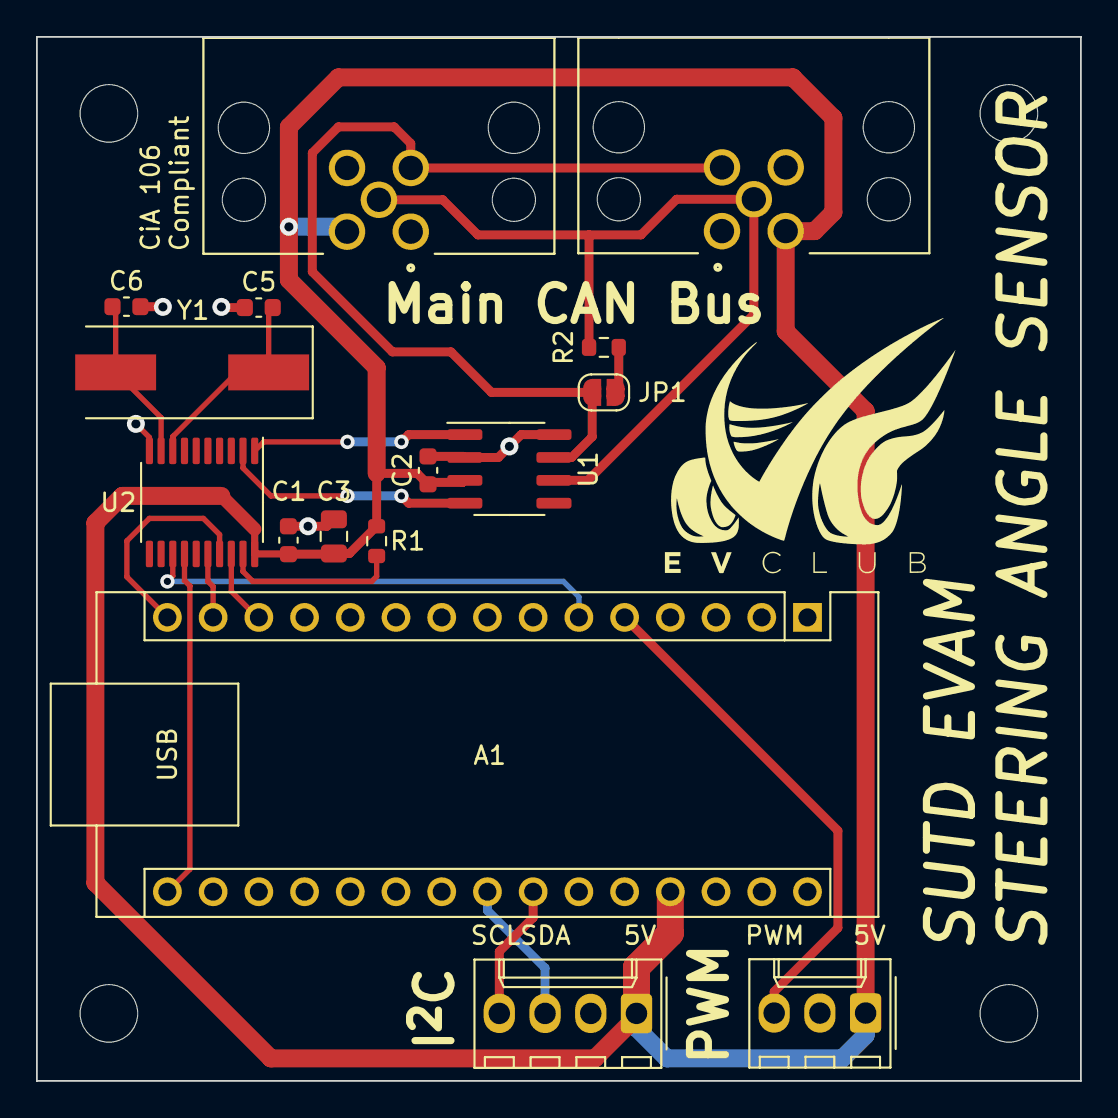
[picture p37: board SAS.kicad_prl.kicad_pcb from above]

Board: 2 copper layers, 58.0 x 58.0 mm, 20 parts (0 on the bottom side), 18 nets.

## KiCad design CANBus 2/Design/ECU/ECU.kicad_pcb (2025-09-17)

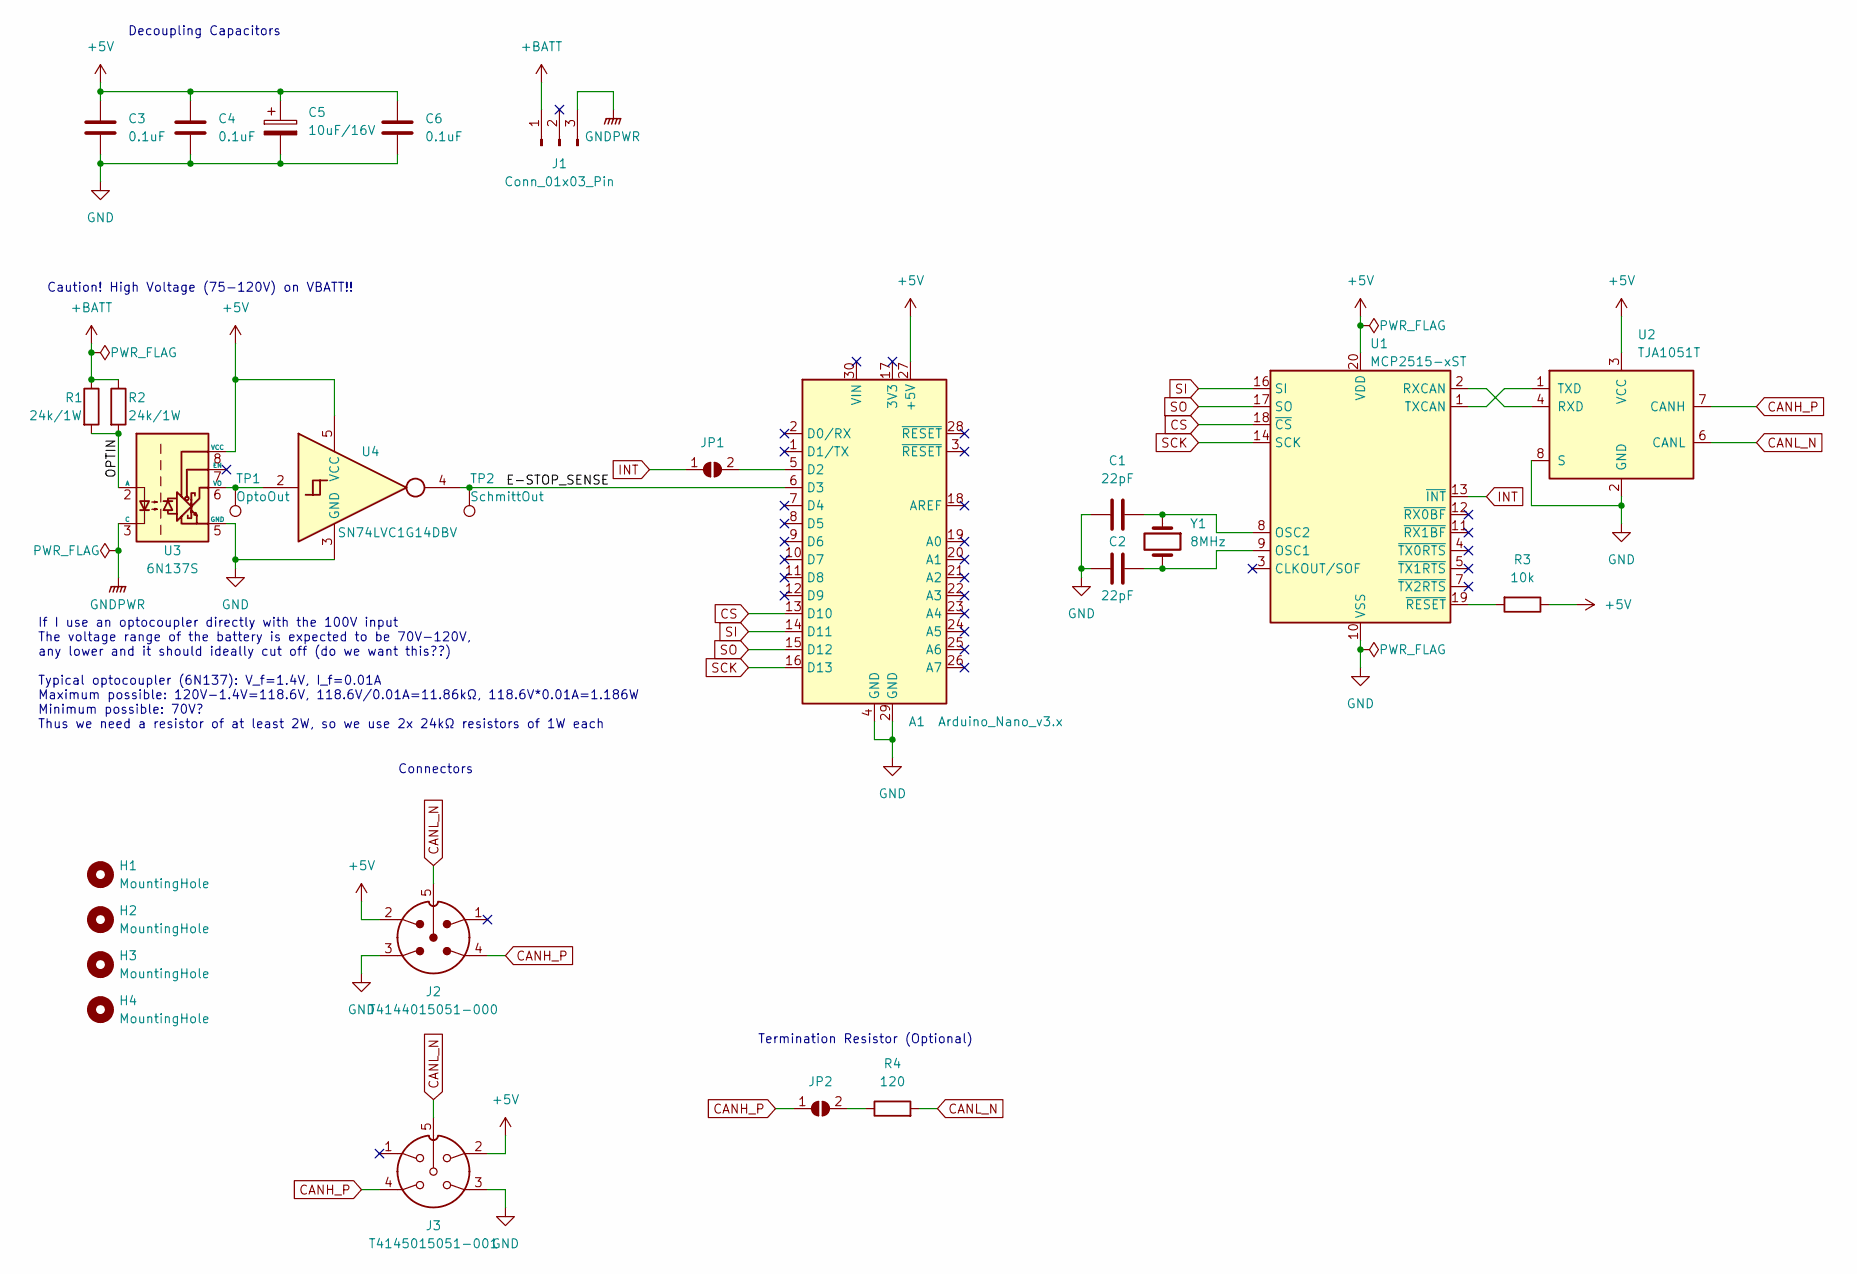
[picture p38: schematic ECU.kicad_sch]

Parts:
A1: Arduino_Nano_v3.x; Arduino_Nano
C1, C2: 22pF; C_0603_1608Metric
C3, C4, C6: 0.1uF; C_0603_1608Metric
C5: 10uF/16V; CP_EIA-3216-18_Kemet-A
H1, H2, H3, H4: MountingHole; MountingHole_3.2mm_M3_ISO14580
J1: Conn_01x03_Pin; Molex_KK-254_AE-6410-03A_1x03_P2.54mm_Vertical
J2: T4144015051-000; M12-P5A-GPL; PARTREV A
J3: T4145015051-001; M12-S5A-GPL; PARTREV A
JP1, JP2: Jumper_2_Open; SolderJumper-2_P1.3mm_Open_RoundedPad1.0x1.5mm
R1, R2: 24k/1W; R_2512_6332Metric
R3: 10k; R_0603_1608Metric
R4: 120; R_0603_1608Metric
TP1: OptoOut; TestPoint_Plated_Hole_D2.0mm
TP2: SchmittOut; TestPoint_Plated_Hole_D2.0mm
U1: MCP2515-xST; TSSOP-20_4.4x6.5mm_P0.65mm
U2: TJA1051T; SOIC-8_3.9x4.9mm_P1.27mm
U3: 6N137S; SMDIP-8_W9.53mm
U4: SN74LVC1G14DBV; SOT-23-5
Y1: 8MHz; Crystal_SMD_HC49-SD

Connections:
+5V: A1.27 (+5V), C3.1, C4.1, C5.1, C6.1, J2.2, J3.2, R3.1, U1.20 (VDD), U2.3 (VCC), U3.8 (VCC), U4.5 (VCC)
+BATT: J1.1, R1.1, R2.1
/E-STOP_SENSE: A1.6 (D3), TP2.1, U4.4
/OPTIN: R1.2, R2.2, U3.2 (A)
CANH_P: J2.4, J3.4, JP2.1 (A), U2.7 (CANH)
CANL_N: J2.5, J3.5, R4.2, U2.6 (CANL)
CS: A1.13 (D10), U1.18 (~CS)
GND: A1.4 (GND), A1.29 (GND), C1.1, C2.2, C3.2, C4.2, C5.2, C6.2, J2.3, J3.3, U1.10 (VSS), U2.2 (GND), U2.8 (S), U3.5 (GND), U4.3 (GND)
GNDPWR: J1.3, U3.3 (C)
INT: JP1.1 (A), U1.13 (~INT)
unnamed: A1.5 (D2), JP1.2 (B)
unnamed: JP2.2 (B), R4.1
unnamed: C2.1, U1.9 (OSC1), Y1.2
unnamed: C1.2, U1.8 (OSC2), Y1.1
unnamed: U1.2 (RXCAN), U2.4 (RXD)
unnamed: U1.1 (TXCAN), U2.1 (TXD)
unnamed: R3.2, U1.19 (~RESET)
unnamed: TP1.1, U3.6 (VO), U4.2
SCK: A1.16 (D13), U1.14 (SCK)
SI: A1.14 (D11), U1.16 (SI)
SO: A1.15 (D12), U1.17 (SO)

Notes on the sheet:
Termination Resistor (Optional)
Connectors
If I use an optocoupler directly with the 100V input The voltage range of the battery is expected to be 70V-120V, any lower and it should ideally cut off (do we want this??) Typical optocoupler (6N137): V_f=1.4V, I_f=0.01A Maximum possible: 120V-1.4V=118.6V, 118.6V/0.01A=11.86kΩ, 118.6V*0.01A=1.186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
Caution! High Voltage (75-120V) on VBATT!!
Decoupling Capacitors

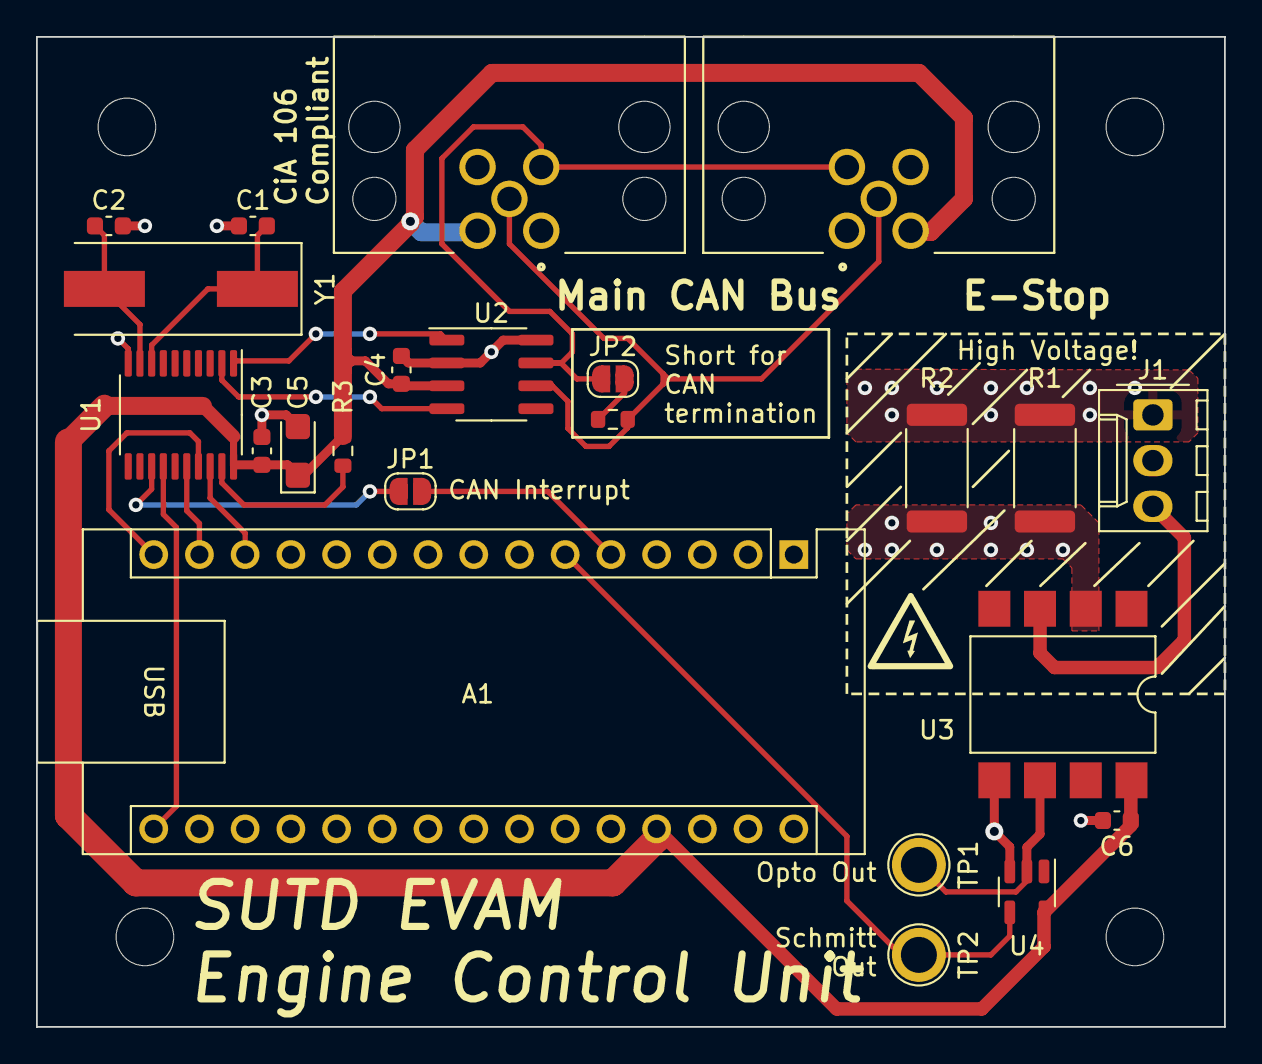
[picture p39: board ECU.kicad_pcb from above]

Board: 2 copper layers, 66.0 x 55.0 mm, 27 parts (0 on the bottom side), 21 nets.

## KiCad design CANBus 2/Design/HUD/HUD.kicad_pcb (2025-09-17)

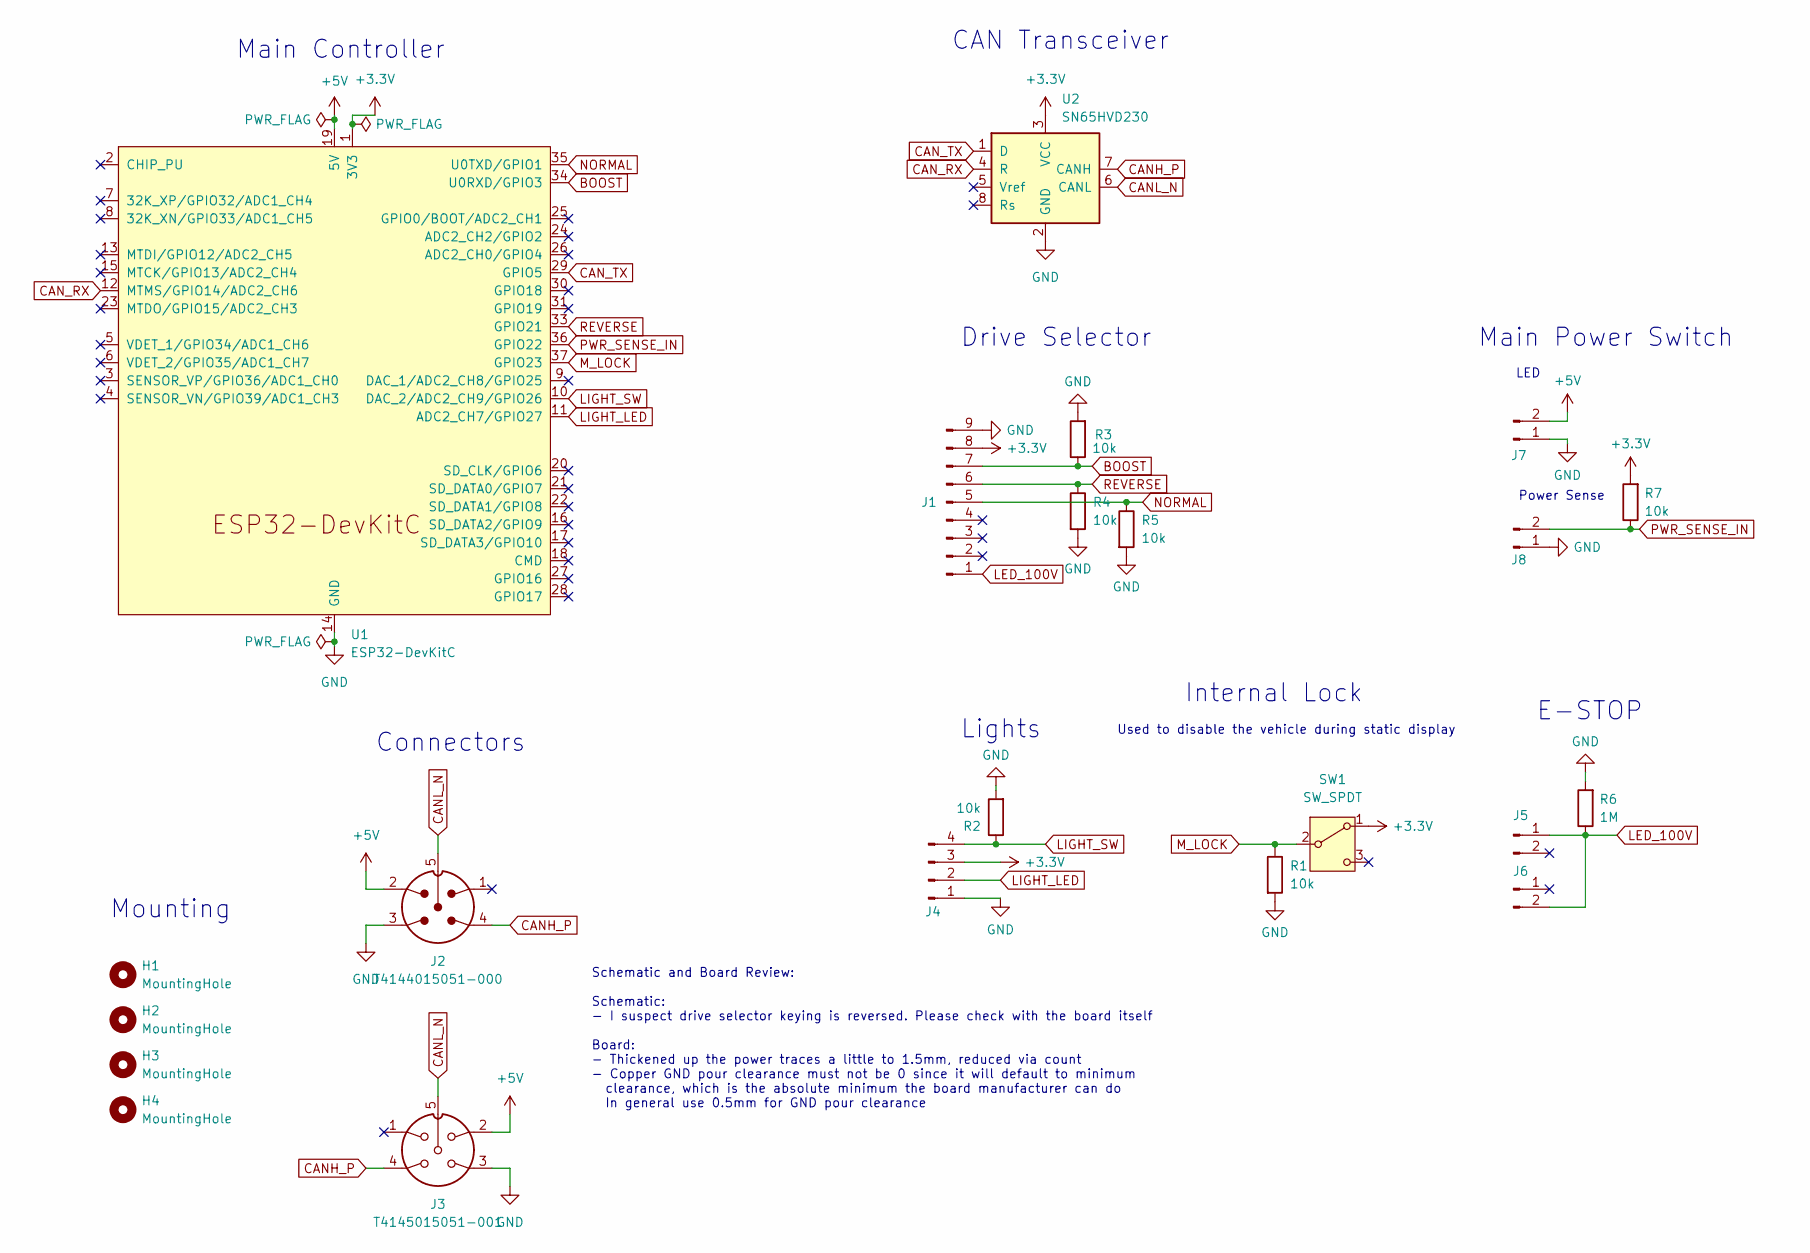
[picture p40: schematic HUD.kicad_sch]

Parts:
H1, H2, H3, H4: MountingHole; MountingHole_3.2mm_M3_ISO14580
J1: Conn_01x09_Pin; Molex_KK-254_AE-6410-09A_1x09_P2.54mm_Vertical
J2: T4144015051-000; M12-P5A-GPL; PARTREV A
J3: T4145015051-001; M12-S5A-GPL; PARTREV A
J4: Conn_01x04_Pin; Molex_KK-254_AE-6410-04A_1x04_P2.54mm_Vertical
J5, J6, J7, J8: Conn_01x02_Pin; Molex_KK-254_AE-6410-02A_1x02_P2.54mm_Vertical
R1, R2, R3, R4, R5, R7: 10k; R_0603_1608Metric
R6: 1M; R_1206_3216Metric
SW1: SW_SPDT; SW_SPDT_MT-0-103-F001-T000-RS
U1: ESP32-DevKitC
U2: SN65HVD230; SOIC-8_3.9x4.9mm_P1.27mm

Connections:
+3.3V: J1.8, J4.3, R7.2, SW1.1 (A), U1.1 (3V3), U2.3 (VCC)
+5V: J2.2, J3.2, J7.2, U1.19 (5V)
BOOST: J1.7, R3.1, U1.34 (U0RXD/GPIO3)
CANH_P: J2.4, J3.4, U2.7 (CANH)
CANL_N: J2.5, J3.5, U2.6 (CANL)
CAN_RX: U1.12 (MTMS/GPIO14/ADC2_CH6), U2.4 (R)
CAN_TX: U1.29 (GPIO5), U2.1 (D)
GND: J1.9, J2.3, J3.3, J4.1, J7.1, J8.1, R1.2, R2.2, R3.2, R4.2, R5.2, R6.2, U1.14 (GND), U1.32 (GND), U1.38 (GND), U2.2 (GND)
LED_100V: J1.1, J5.1, J6.2, R6.1
LIGHT_LED: J4.2, U1.11 (ADC2_CH7/GPIO27)
LIGHT_SW: J4.4, R2.1, U1.10 (DAC_2/ADC2_CH9/GPIO26)
M_LOCK: R1.1, SW1.2 (B), U1.37 (GPIO23)
NORMAL: J1.5, R5.1, U1.35 (U0TXD/GPIO1)
PWR_SENSE_IN: J8.2, R7.1, U1.36 (GPIO22)
REVERSE: J1.6, R4.1, U1.33 (GPIO21)

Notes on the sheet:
Used to disable the vehicle during static display
Lights
CAN Transceiver
Schematic and Board Review: Schematic: - I suspect drive selector keying is reversed. Please check with the board itself Board: - Thickened up the power traces a little to 1.5mm, reduced via count - Copper GND pour clearance must not be 0 since it will default to minimum clearance, which is the abs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
LED
Power Sense
Mounting
Main Controller
E-STOP
Main Power Switch
Connectors
Internal Lock
Drive Selector

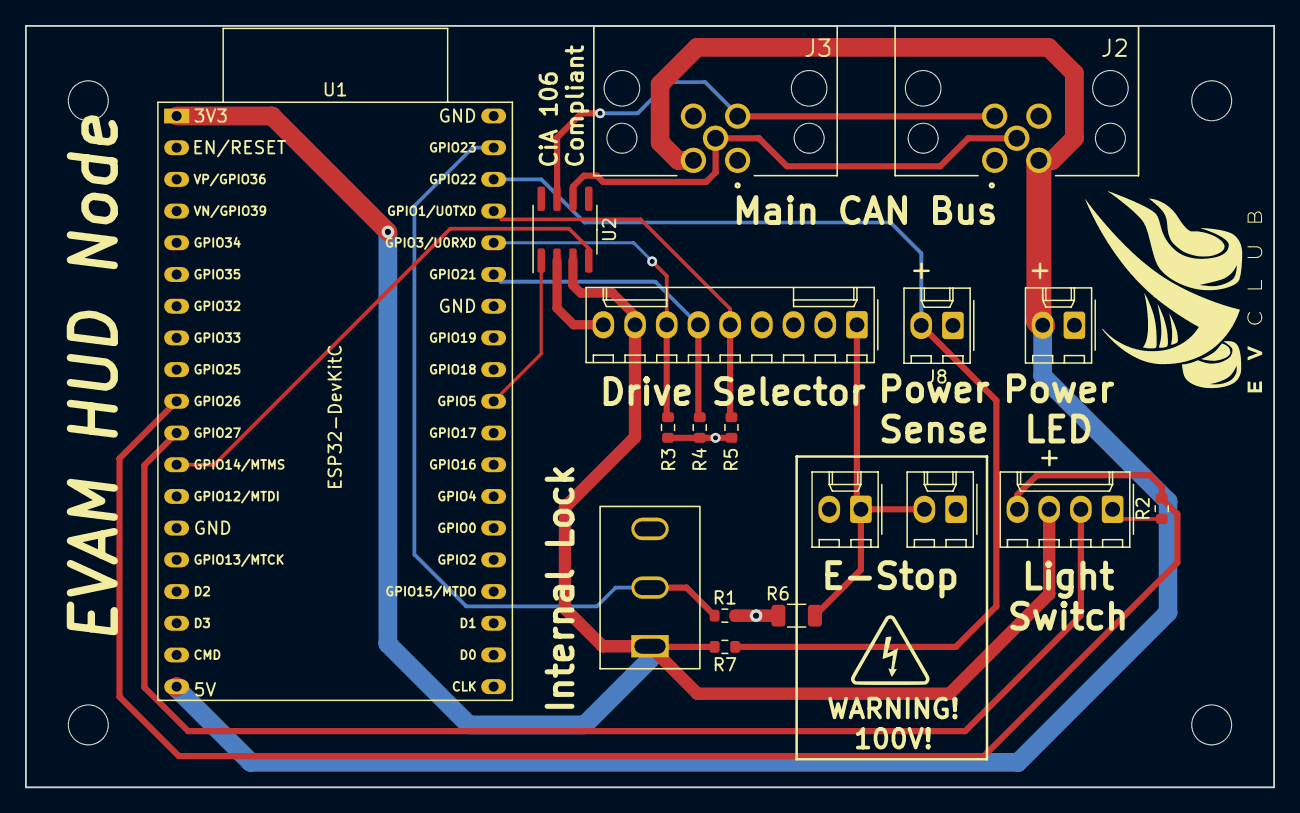
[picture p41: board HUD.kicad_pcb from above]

Board: 2 copper layers, 100.0 x 61.0 mm, 22 parts (0 on the bottom side), 15 nets.

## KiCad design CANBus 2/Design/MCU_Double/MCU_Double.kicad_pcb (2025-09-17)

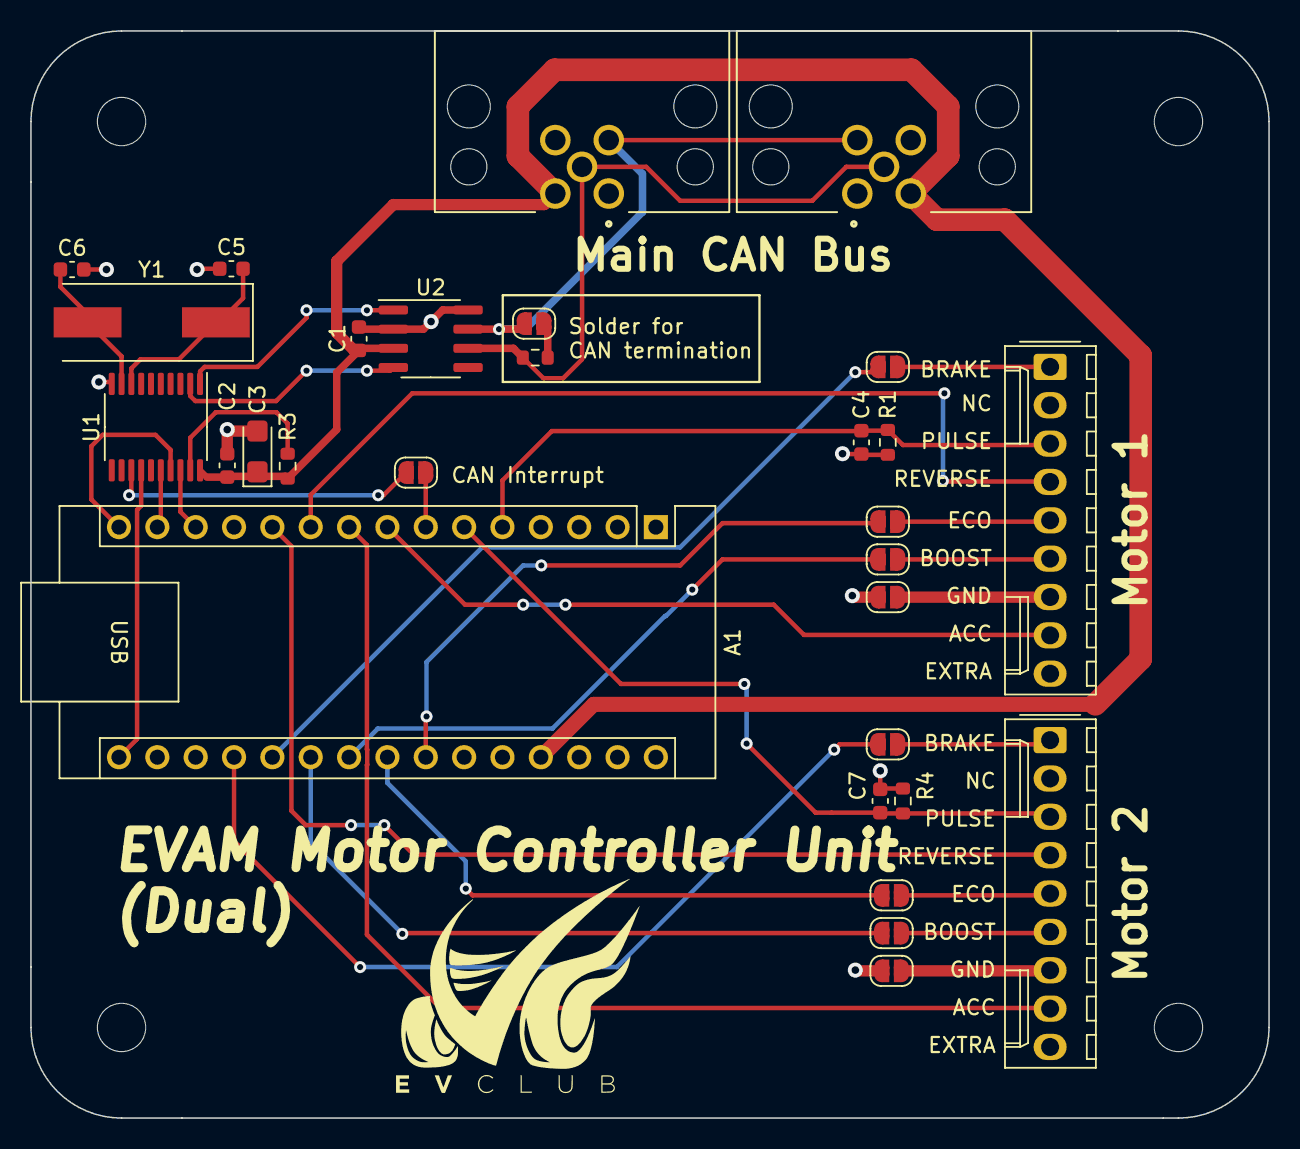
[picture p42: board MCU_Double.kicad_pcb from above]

Board: 2 copper layers, 82.0 x 72.0 mm, 33 parts (0 on the bottom side), 36 nets.

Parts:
A1: Arduino_Nano_v3.x; Arduino_Nano
C1, C2: 0.1uF; C_0603_1608Metric
C3: 10uF/16V; CP_EIA-3216-18_Kemet-A
C4, C7: 1nF; C_0603_1608Metric
C5, C6: 22pF; C_0603_1608Metric
H1, H2, H3, H4: MountingHole; MountingHole_3.2mm_M3_ISO14580
J1, J4: Conn_01x09_Pin; Molex_KK-254_AE-6410-09A_1x09_P2.54mm_Vertical
J2: T4144015051-000; M12-P5A-GPL
J3: T4145015051-001; M12-S5A-GPL
JP1, JP2, JP3, JP4, JP5, JP6, JP7, JP8, JP9, JP10: Jumper_2_Open; SolderJumper-2_P1.3mm_Open_RoundedPad1.0x1.5mm
R1, R4: 1M; R_0603_1608Metric
R2: 120; R_0603_1608Metric
R3: 10k; R_0603_1608Metric
U1: MCP2515-xST; TSSOP-20_4.4x6.5mm_P0.65mm
U2: TJA1051T; SOIC-8_3.9x4.9mm_P1.27mm
Y1: 8MHz; Crystal_SMD_HC49-SD

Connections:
+5V: A1.27 (+5V), C1.1, C2.1, C3.1, J2.2, J3.2, R3.1, U1.20 (VDD), U2.3 (VCC)
ACC_1: A1.8 (D5), J1.8
ACC_2: A1.9 (D6), J4.8
BOOST: A1.22 (A3), JP3.2 (B)
BOOST2: A1.21 (A2), JP9.2 (B)
CANH_P: J2.4, J3.4, JP6.1 (A), U2.7 (CANH)
CANL_N: J2.5, J3.5, R2.2, U2.6 (CANL)
CS: A1.13 (D10), U1.18 (~CS)
ECO: A1.24 (A5), JP4.2 (B)
ECO2: A1.23 (A4), JP10.2 (B)
GND: A1.4 (GND), A1.29 (GND), C1.2, C2.2, C3.2, C4.2, C5.1, C6.2, C7.2, J2.3, J3.3, JP1.2 (B), JP7.2 (B), R1.2, R4.2, U1.10 (VSS), U2.2 (GND), U2.8 (S)
INT: JP5.1 (A), U1.13 (~INT)
LOCK: A1.20 (A1), JP2.2 (B)
LOCK2: A1.19 (A0), JP8.2 (B)
unnamed: A1.7 (D4), JP5.2 (B)
unnamed: J1.1, JP2.1 (A)
unnamed: J1.5, JP4.1 (A)
unnamed: J1.6, JP3.1 (A)
unnamed: J1.7, JP1.1 (A)
unnamed: J4.1, JP8.1 (A)
unnamed: J4.5, JP10.1 (A)
unnamed: J4.6, JP9.1 (A)
unnamed: J4.7, JP7.1 (A)
unnamed: JP6.2 (B), R2.1
unnamed: C6.1, U1.9 (OSC1), Y1.2
unnamed: C5.2, U1.8 (OSC2), Y1.1
unnamed: U1.2 (RXCAN), U2.4 (RXD)
unnamed: U1.1 (TXCAN), U2.1 (TXD)
unnamed: R3.2, U1.19 (~RESET)
PULSE: A1.5 (D2), C4.1, J1.3, R1.1
PULSE2: A1.6 (D3), C7.1, J4.3, R4.1
REVERSE: A1.10 (D7), J1.4
REVERSE2: A1.11 (D8), J4.4
SCK: A1.16 (D13), U1.14 (SCK)
SI: A1.14 (D11), U1.16 (SI)
SO: A1.15 (D12), U1.17 (SO)

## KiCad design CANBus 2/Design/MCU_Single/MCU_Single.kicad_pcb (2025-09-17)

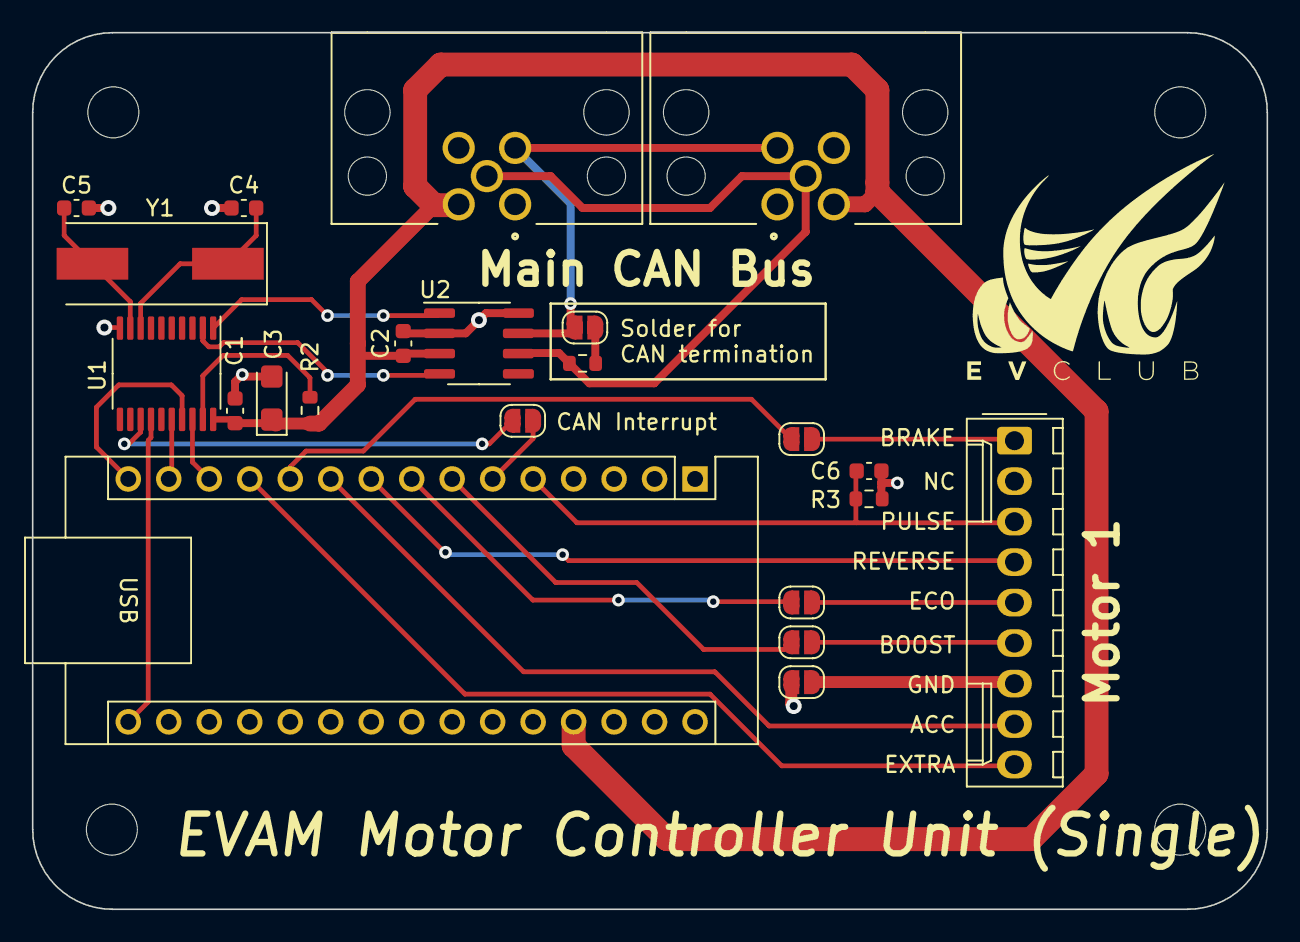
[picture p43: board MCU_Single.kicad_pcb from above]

Board: 2 copper layers, 77.5 x 55.0 mm, 26 parts (0 on the bottom side), 27 nets.

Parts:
A1: Arduino_Nano_v3.x; Arduino_Nano
C1, C2: 0.1uF; C_0603_1608Metric
C3: 10uF/16V; CP_EIA-3216-18_Kemet-A
C4, C5: 22pF; C_0603_1608Metric
C6: 1nF; C_0603_1608Metric
H1, H2, H3, H4: MountingHole; MountingHole_3.2mm_M3_ISO14580
J1: Conn_01x09_Pin; Molex_KK-254_AE-6410-09A_1x09_P2.54mm_Vertical
J2: T4144015051-000; M12-P5A-GPL
J3: T4145015051-001; M12-S5A-GPL
JP1, JP2, JP3, JP4, JP5, JP6: Jumper_2_Open; SolderJumper-2_P1.3mm_Open_RoundedPad1.0x1.5mm
R1: 120; R_0603_1608Metric
R2: 10k; R_0603_1608Metric
R3: 1M; R_0603_1608Metric
U1: MCP2515-xST; TSSOP-20_4.4x6.5mm_P0.65mm
U2: TJA1051T; SOIC-8_3.9x4.9mm_P1.27mm
Y1: 8MHz; Crystal_SMD_HC49-SD

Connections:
+5V: A1.27 (+5V), C1.1, C2.1, C3.1, J2.2, J3.2, R2.1, U1.20 (VDD), U2.3 (VCC)
ACC_1: A1.10 (D7), J1.8
BOOST: A1.7 (D4), JP4.2 (B)
CANH_P: J2.4, J3.4, JP2.1 (A), U2.7 (CANH)
CANL_N: J2.5, J3.5, R1.2, U2.6 (CANL)
CS: A1.13 (D10), U1.18 (~CS)
ECO: A1.8 (D5), JP5.2 (B)
EXTRA_1: A1.12 (D9), J1.9
GND: A1.4 (GND), A1.29 (GND), C1.2, C2.2, C3.2, C4.1, C5.2, C6.2, J2.3, J3.3, JP3.2 (B), R3.2, U1.10 (VSS), U2.2 (GND), U2.8 (S)
INT: JP1.1 (A), U1.13 (~INT)
LOCK: A1.11 (D8), JP6.2 (B)
unnamed: A1.6 (D3), JP1.2 (B)
unnamed: J1.1, JP6.1 (A)
unnamed: J1.5, JP5.1 (A)
unnamed: J1.6, JP4.1 (A)
unnamed: J1.7, JP3.1 (A)
unnamed: JP2.2 (B), R1.1
unnamed: C5.1, U1.9 (OSC1), Y1.2
unnamed: C4.2, U1.8 (OSC2), Y1.1
unnamed: U1.2 (RXCAN), U2.4 (RXD)
unnamed: U1.1 (TXCAN), U2.1 (TXD)
unnamed: R2.2, U1.19 (~RESET)
PULSE: A1.5 (D2), C6.1, J1.3, R3.1
REVERSE: A1.9 (D6), J1.4
SCK: A1.16 (D13), U1.14 (SCK)
SI: A1.14 (D11), U1.16 (SI)
SO: A1.15 (D12), U1.17 (SO)

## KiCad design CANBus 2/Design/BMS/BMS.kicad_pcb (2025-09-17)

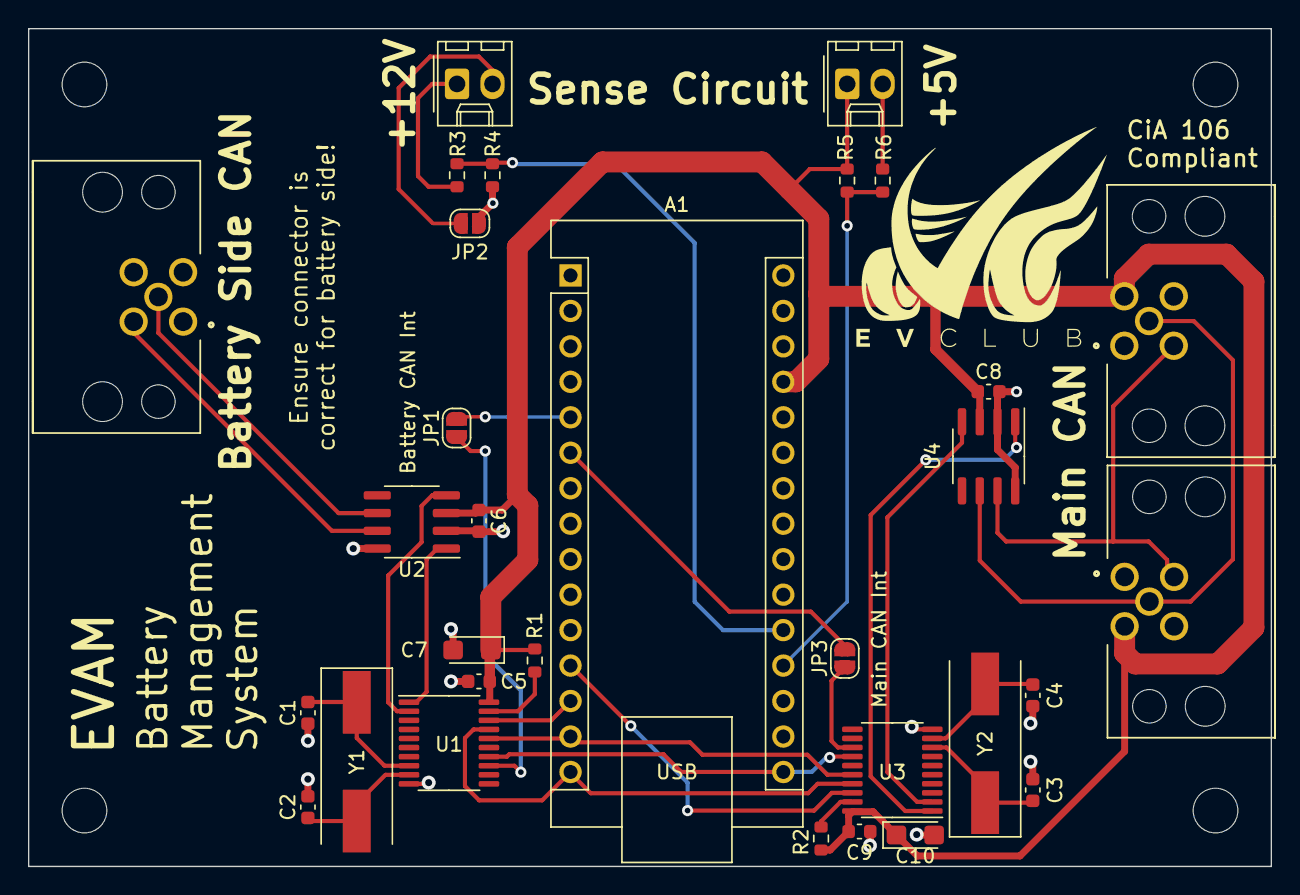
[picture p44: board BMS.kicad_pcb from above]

Board: 2 copper layers, 89.0 x 60.0 mm, 35 parts (0 on the bottom side), 29 nets.

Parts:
A1: Arduino_Nano_v3.x; Arduino_Nano
C1, C2, C3, C4: 22pF; C_0603_1608Metric
C5, C6, C8, C9: 0.1uF; C_0603_1608Metric
C7, C10: 10uF/16V; CP_EIA-3216-18_Kemet-A
H1, H2, H3, H4: MountingHole; MountingHole_3.2mm_M3_ISO14580
J1, J3: T4144015051-000; M12-P5A-GPL
J2: T4145015051-001; M12-S5A-GPL
J4, J5: Conn_01x02_Pin; Molex_KK-254_AE-6410-02A_1x02_P2.54mm_Vertical
JP1, JP2, JP3: SolderJumper_2_Open; SolderJumper-2_P1.3mm_Open_RoundedPad1.0x1.5mm
R1, R2, R3, R5, R6: 10k; R_0603_1608Metric
R4: 2.7k; R_0603_1608Metric
U1, U3: MCP2515-xST; TSSOP-20_4.4x6.5mm_P0.65mm
U2, U4: TJA1051T; SOIC-8_3.9x4.9mm_P1.27mm
Y1, Y2: 8MHz; Crystal_SMD_HC49-SD

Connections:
5V_Sense: A1.19 (A0), R5.2, R6.1
12V_Sense: A1.20 (A1), R3.2, R4.1
+5V: A1.27 (+5V), C5.1, C6.1, C7.1, C8.1, C9.1, C10.1, J1.2, J2.2, J4.1, R1.1, R2.1, R5.1, U1.20 (VDD), U2.3 (VCC), U3.20 (VDD), U4.3 (VCC)
+12V: J5.1, R3.1
CANH_P: J1.4, J2.4, U4.7 (CANH)
CANH_P_BATT: J3.4, U2.7 (CANH)
CANL_N: J1.5, J2.5, U4.6 (CANL)
CANL_N_BATT: J3.5, U2.6 (CANL)
CS_BATT: A1.13 (D10), U1.18 (~CS)
CS_CAR: A1.12 (D9), U3.18 (~CS)
GND: A1.4 (GND), A1.29 (GND), C1.1, C2.2, C3.1, C4.2, C5.2, C6.2, C7.2, C8.2, C9.2, C10.2, J1.3, J2.3, J3.3, J4.2, JP2.2 (B), R4.2, R6.2, U1.10 (VSS), U2.2 (GND), U2.8 (S), U3.10 (VSS), U4.2 (GND), U4.8 (S)
INT_BATT: JP1.1 (A), U1.13 (~INT)
INT_CAR: JP3.1 (A), U3.13 (~INT)
unnamed: A1.5 (D2), JP1.2 (B)
unnamed: A1.6 (D3), JP3.2 (B)
unnamed: J5.2, JP2.1 (A)
unnamed: C2.1, U1.9 (OSC1), Y1.2
unnamed: C1.2, U1.8 (OSC2), Y1.1
unnamed: U1.2 (RXCAN), U2.4 (RXD)
unnamed: U1.1 (TXCAN), U2.1 (TXD)
unnamed: R1.2, U1.19 (~RESET)
unnamed: C4.1, U3.9 (OSC1), Y2.2
unnamed: C3.2, U3.8 (OSC2), Y2.1
unnamed: U3.2 (RXCAN), U4.4 (RXD)
unnamed: U3.1 (TXCAN), U4.1 (TXD)
unnamed: R2.2, U3.19 (~RESET)
SCK: A1.16 (D13), U1.14 (SCK), U3.14 (SCK)
SI: A1.14 (D11), U1.16 (SI), U3.16 (SI)
SO: A1.15 (D12), U1.17 (SO), U3.17 (SO)

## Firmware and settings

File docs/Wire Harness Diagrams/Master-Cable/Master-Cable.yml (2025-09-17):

metadata:
  title: Master-Cable
  authors:
    Created:
      name: EVAM
      date: 2025-08-20

connectors:
  C1:
    # General
    type: GX16-6 Reverse Type
    subtype: Male
    image:
      src: img/GX16-Rev-pinout-cable.png
      width: 300
    notes: Cable side is shown; please double check CAN+ and -

    # Purchase
    ignore_in_bom: false
    manufacturer: Renhotec
    mpn: GX16-A-6-P
    supplier: Aliexpress
    spn: 1005008016363970

    # Pinout
    pins: [1, 2, 3, 4, 5, 6]
    pinlabels: [SW+ (switch+), SW- (switch-), HV (100V!), GND, CAN+, CAN-]

  C2:
    # General
    type: M12 A-key
    subtype: Female
    image:
      src: img/M12-Diagram-CANCiA106.png
      width: 350
    notes: Cable side is shown

    # Purchase
    ignore_in_bom: false
    manufacturer: CAZN
    mpn: M12-S-GWB
    supplier: Taobao
    spn: 

    # Pinout
    pincount: 6
    pinlabels: ['1','2','3','4','5','6']
  
  C3:
    # General
    type: JST RCY
    subtype: Receptacle
    image:
      src: img/JST-RCY-pinout-receptacle.png # placeholder
      width: 400
    notes: Cable side is shown

    # Purchase
    ignore_in_bom: false
    manufacturer: JST
    mpn: SYR-02T
    supplier: DigiKey
    spn: 455-2653-ND

    # Pinout
    pincount: 2
    pinlabels: [J1, J2] # J1 is not implemented

  C4:
    # General
    type: JST RCY
    subtype: Plug
    image:
      src: img/JST-RCY-pinout-plug.png # placeholder
      width: 400
    notes: Cable side is shown

    # Purchase
    ignore_in_bom: false
    manufacturer: JST
    mpn: SYR-02T
    supplier: DigiKey
    spn: 455-2653-ND

    # Pinout
    pincount: 2
    pinlabels: [J1, J2] # J1 is not implemented

  C5:
    # General
    type: JST RCY
    subtype: Plug
    image:
      src: img/JST-RCY-pinout.png # placeholder
      width: 400
    notes: Cable side is shown

    # Purchase
    ignore_in_bom: false
    manufacturer: JST
    mpn: SYR-02T
    supplier: DigiKey
    spn: 455-2653-ND

    # Pinout
    pincount: 2
    pinlabels: [J1, J2] # J1 is not implemented

  C6:
    # General
    type: JST RCY
    subtype: Receptacle
    image:
      src: img/JST-RCY-pinout.png # placeholder
      width: 400
    notes: Cable side is shown

    # Purchase
    ignore_in_bom: false
    manufacturer: JST
    mpn: SYR-02T
    supplier: DigiKey
    spn: 455-2653-ND

    # Pinout
    pincount: 2
    pinlabels: [J1, J2] # J1 is not implemented

  C7:
    # General
    type: JST RCY
    subtype: Plug
    image:
      src: img/JST-RCY-pinout.png # placeholder
      width: 400
    notes: Cable side is shown

    # Purchase
    ignore_in_bom: false
    manufacturer: JST
    mpn: SYR-02T
    supplier: DigiKey
    spn: 455-2653-ND

    # Pinout
    pincount: 2
    pinlabels: [J1, J2] # J1 is not implemented

  C8:
    # General
    type: JST RCY
    subtype: Plug
    image:
      src: img/JST-RCY-pinout-plug.png # placeholder
      width: 400
    notes: Cable side is shown

    # Purchase
    ignore_in_bom: false
    manufacturer: JST
    mpn: SYR-02T
    supplier: DigiKey
    spn: 455-2653-ND

    # Pinout
    pincount: 2
    pinlabels: [J1, J2] # J1 is not implemented

  HS1: # this is a piece of heat shrink'd solder joint
    style: simple
    type: Heat shrink solder joint
    subtype: 22 AWG

  HS2: # this is a piece of heat shrink'd solder joint
    style: simple
    type: Heat shrink solder joint
    subtype: 22 AWG

  HS3: # this is a piece of heat shrink'd solder joint
    style: simple
    type: Heat shrink solder joint
    subtype: 22 AWG

  HS4: # this is a piece of heat shrink'd solder joint
    style: simple
    type: Heat shrink solder joint
    subtype: 22 AWG

  SW1: # this is a side e-stop switch
    style: simple
    type: E-Stop Switch
    subtype: 22 AWG

  HS5: # this is a piece of heat shrink'd solder joint
    style: simple
    type: Heat shrink solder joint
    subtype: 22 AWG

  HS6: # this is a piece of heat shrink'd solder joint
    style: simple
    type: Heat shrink solder joint
    subtype: 22 AWG

  E1: # exposed section
    style: simple
    type: exposed section
    subtype: 22 AWG

  F1: # fork terminal
    style: simple
    type: Fork terminal
    color: RD
    subtype: 22 AWG

  F2: # fork terminal
    style: simple
    type: Fork terminal
    color: BK
    subtype: 22 AWG

  E2: # exposed section
    style: simple
    type: exposed section
    subtype: 22 AWG

  E3: # exposed section
    style: simple
    type: exposed section
    subtype: 22 AWG

cables:
  W1:
    gauge: 22 AWG
    length: 0.5 m
    colors: [BN, WH, RD, BK, YE, GN]
  
  W2:
    gauge: 22 AWG
    length: 0.1 m
    colors: [RD]
    wirecount: 1

<<<<<<< HEAD
  W3:
    gauge: 22 AWG
    length: 0.1 m
    colors: [BK, GY]
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

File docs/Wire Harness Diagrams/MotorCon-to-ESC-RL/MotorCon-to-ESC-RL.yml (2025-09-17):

metadata:
  title: MotorCon-to-ESC-RL
  authors:
    Created:
      name: EVAM
      date: 2025-08-06

connectors:
  C1:
    # General
    type: Aptiv SICMA
    subtype: Female
    image:
      src: img/Delphi-24-pinout.png
      width: 400
    notes: Device side diagram is shown

    # Purchase
    ignore_in_bom: false
    manufacturer: Aptiv (formerly Delphi)
    mpn: 211PC249S0031
    supplier: Mouser
    spn: 649-211PC249S0031

    # Pinout
    pincount: 24
    pins: [A1, A2, A3, A4, A5, A6, A7, A8, B1, B2, B3, B4, B5, B6, B7, B8, C1, C2, C3, C4, C5, C6, C7, C8]
    pinlabels: [RTN (High Voltage Power Negative), 12V+ (for relay), ACC+ (DC+ for Accelerator), STL (~Stop), BST (Boost), OUT (Logic out), 1HC (Hall sensor C), VH (DC+ for Hall sensor), Vkey (Power on), L- (relay signal), ACC-OUT (Accelerator), R (Reverse), IN1 (Eco), MS (Pulse output), 1HB (Hall sensor B), THM (Motor thermistor), NC, 12V-, STH (Stop), F (Forward), ALM (~Motor Lock), BEMF (Back EMF), 1HA (Hall sensor A), RTN (High Voltage Power GND)]

  C2:
    # General
    type: Furukawa RFW
    subtype: Female
    image:
      src: img/FW-C-6F-B-pinout.png
      width: 350
    notes: Cable side is shown

    # Purchase
    ignore_in_bom: false
    manufacturer: Furukawa
    mpn: FW-C-6F-B
    supplier: Aliexpress
    spn: DJ7061Y-2.3-11

    # Pinout
    pincount: 6
    pinlabels: [H1,H2,H3,H4,H5,H6]
  
  C3:
    # General
    type: Molex KK254
    subtype: Female
    image:
      src: img/MolexKK254-9-pinout.png
      width: 300
    notes: Cable side is shown

    # Purchase
    ignore_in_bom: false
    manufacturer: Molex
    mpn: 22013097
    supplier: DigiKey
    spn: WM2007-MD

    # Pinout
    pincount: 9
    pinlabels: [LOCK,NC,PULSE,REVERSE,ECO,BOOST,GND,ACC,EXTRA]
  
  # TODO: Check if C4 is defined correctly
  C4:
    # General
    type: JST RCY
    subtype: Plug
    image:
      src: img/JST-RCY-pinout-plug.png
      width: 400
    notes: Cable side is shown

    # Purchase
    ignore_in_bom: false
    manufacturer: JST
    mpn: SYR-02T
    supplier: DigiKey
    spn: 455-2653-ND

    # Pinout
    pincount: 2
    pinlabels: [J1, J2] # J1 is not implemented
  
  HS1: # this is a piece of heat shrink'd solder joint
    style: simple
    type: Heat shrink solder joint
    subtype: 22 AWG

cables:
  W1:
    category: bundle
    gauge: 22 AWG
    length: 0.5 m
    colors: [GNBK, BN, BU, RD, PK, YEBK, VT, GYBK, YEGN, GN, WH, YE, BK, BK] # Note that VT is actually sky blue
    notes: "NOTE: VT is actually sky blue"
  
  W2:
    gauge: 22 AWG
    length: 0.1 m
    colors: [RD]
    wirecount: 1

connections:
# If using Anaconda to manage Python environments, 
# please activate conda environment wireviz before compiling
  - # C1 to C2
    - C1: [A7, A8, B7, B8, C7, C8]
    - W1: [3, 4, 10, 11, 12, 13]
    - C2: [3, 4, 2, 5, 1, 6]
  
  - # C1 to C3
    - C1: [A4, A5, B3, B4, B5, B6, A1]
    - W1: [1, 2, 6, 7, 8, 9, 14]
    - C3: [1, 6, 4, 8, 5, 3, 7]

  - # C1 to C4
    - C1: [B1]
    - W1: [5]
    - HS1: [1]
    - W2: [1]
    - C4: [2]

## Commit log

2025-05-19 initial commit of all relevant assets to EVAM canbus 2
    [APPS (Throttle Position Sensor).kicad_pcb, APPS (Throttle Position Sensor).kicad_sch, APPS (Throttle Position Sensor).step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]
2025-08-08 added first wire harness diagram
    [MotorCon-to-ESC-RL.bom.tsv, MotorCon-to-ESC-RL.yml]
2025-08-08 added new connection for wire diagram
    [MotorCon-to-ESC-RL.yml]
2025-08-08 did wiring for all connections except JST RCY
    [MotorCon-to-ESC-RL.yml]
2025-08-08 inserted placeholder for JST RCY connector
    [MotorCon-to-ESC-RL.yml]
2025-08-08 defined JST RCY connector
    [MotorCon-to-ESC-RL.yml]
2025-08-08 corrected model number for JST RCY
    [MotorCon-to-ESC-RL.yml]
2025-08-09 added images for the motor wire harness
    [MotorCon-to-ESC-RL.bom.tsv, MotorCon-to-ESC-RL.yml]
2025-08-12 completed motor RL diagram
    [MotorCon-to-ESC-RL.yml]
2025-08-14 fixed furukawa and JST RCY pinouts
    [MotorCon-to-ESC-RL.bom.tsv, MotorCon-to-ESC-RL.yml]
2025-08-22 new master cable diagram (incomplete!)
    [Master-Cable.bom.tsv]
2025-09-08 preliminary edits to the master cable diagram
    [Master-Cable.bom.tsv]
2025-09-08 added M12 connector diagram for CAN CiA106 standard
2025-09-08 updated M12 connector picture in diagram
    [Master-Cable.bom.tsv]
2025-09-09 added E-stop connections to master cable
    [Master-Cable.bom.tsv]
2025-09-09 more edits to master cable diagram(?), but estop switch currently displayed with placeholder W10. RCY female male stuff may be dodgy
    [Master-Cable.bom.tsv]
2025-09-09 updated all JST RCY images
    [MotorCon-to-ESC-RL.bom.tsv, MotorCon-to-ESC-RL.yml]
2025-09-16 fixed 3d models with new envvar
    [APPS (Throttle Position Sensor).kicad_pcb, BMS.kicad_pcb, ECU.kicad_pcb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]
2025-09-25 overall system wiring png and draw.io file
2026-02-26 added new HUD dashboard files
    [HUD-Dashboard-B_Cu.gbl, HUD-Dashboard-B_Mask.gbs, HUD-Dashboard-B_Paste.gbp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]
